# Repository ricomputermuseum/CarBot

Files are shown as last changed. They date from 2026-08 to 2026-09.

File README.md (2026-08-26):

# RICM-CarBot
This contains the Source code, Documentation, Bill of Materials, & 3D STL file for the CarBot from the Rhode Island Computer Museum. 
The code requires a Raspberry Pi Pico-W. Usually runs with a custom PCB that has two motor drivers and female headers that you can experiment with. 
The code is written for Micropython and you can use Thonny as the IDE. 

All software in the Software directory and lib/ of this repository needs to be copied to the Pico's root directory

Included is a Bill Of Materials (BOM) and a PDF for assembly and operation

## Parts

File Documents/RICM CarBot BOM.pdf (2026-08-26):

RICM Robot Car kit BOM
Qty | Item
1 | Metal car Chassis
2 | Wheels
2 | Motors w/screws & nuts
1 | Guide roller w/screws
1 | (3) AA Battery Pack w/3 pin dupont connector
3 | AA Batteries (not included)
1 | Raspberry Pi Pico W
1 | A2 3d Plastic Adapter plate (stl file)
12 | M3 x 8mm Philips Pan Washer Head (PWH) Screws
4 | M3 x 25mm plastic Standoffs
4 | Female Dupont to bare ends 20mm
1 | Diode (blue with black line)
1 | 4.7K Resistor (yellow-purple-red)
1 | 220 ohm Resistor (red-red-brown)
1 | 3mm LED
1 | Push Button Switch
2 | 8pin DIP socket
2 | L9110 IC
3 | .1uf capacitor
4 | 20 pin Female Hdr
2 | 20 pin Male Hdr
1 | 3 pin Male hdr
1 | 20pin right angle IDC connector
1 | RICM Printed Circuit Board (PCB)

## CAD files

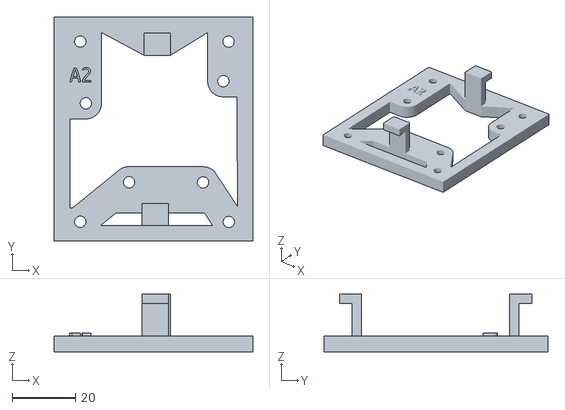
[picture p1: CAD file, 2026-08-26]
Documents/RICM CarBot-A2.stl
63.0 x 71.0 x 18.2

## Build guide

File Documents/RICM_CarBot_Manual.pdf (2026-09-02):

### RICM CarBot

(ricomputermuseum.org)

Goal:
Create a modifiable 2 wheeled robot capable of currently 4 functions:
- Ability to be remotely controlled using any web browser
- Autonomous operation by collision avoidance
- Ability to follow a thick black line
- Ability to travel in a programmed pattern.
The robot is to be built by students from age 8 on up using standard mechanical components, screws, motors, plastic components. Students will also learn how to solder a custom-built printed circuit which will be the basis of expandability and provide support circuitry to control motors and other sensors. You can switch modes with a small push button located on the custom printed circuit board. An onboard green LED flashes to indicate the selected modes. You can change mode anytime.

Hardware:
The “brains” of the robot car is a pre-programmed Raspberry Pi Pico W. The Pico was selected due to its ability to avoid program corruption when power is removed, and its size. RICM needed to have a board that the Pico could plug into that also had an onboard motor controller capable of driving wheel motors from 2.5 – 12 volts at 800ma of current per motor. No readily available boards were located that fit our needs, so RICM developed their own PCB. This custom PCB has mounting place in the middle for the Pico, (2) L9110 motor drivers, a power LED, a pushbutton. It also includes power pins for 3.3 V and 5 V as well as associated grounds to provide power to other devices such as sensors, lights etc.
The board uses GPIO pins for hardware interfacing, GPIO-14 for the pushbutton, GPIO-18-19 for the right motor and GPIO-20-21 for the left motor, for a total of 5 GPIO pins, leaving many more GPIO pins for expansion & experimentation. No external wires are needed to connect the motor drivers to the Pico as they are permanently assigned on the PCB.
On the Pico, there are also (3) analog to digital converters (ADC). The Pico uses these to convert analog signals or varying voltage, represented as numbers (0-4096) to be used for working with sensors that operate with analog voltages. These ADCs need a reference voltage to set the analog voltage against. Therefore, the custom PCB connects

1

the regulated 3.3 V of the Pico to the reference voltage of the ADCs. so the ADCs can convert analog voltages from 0 to 3.3 V to a number between 0-4096! The reference voltage can be changed by cutting a bowtie looking PCB trace and supplying the ADCs with another voltage reference. The new voltage reference must be very stable, so it is not recommended this should be done, unless you know what you are doing.
The motors will operate from 1.5 to 6 V, thus making for easy & simple battery operation. The car uses (3) AA batteries producing 4.5 V to the board and motors. The Pico needs 1.8 to 5.5 V to operate, so this battery pack is ideal for both the Pico and the motors.
The custom PCB mounts to a 3D-printed adapter plate, that is raised up so battery pack can slide under it. Software is all open source and can be modified using standard Python language at will by the student, or used as-is. All hardware, except the custom motor driver board, is readily available, as off-the-shelf parts.

Software:
With the small exception of HTML & JavaScript used for the remote control section, and pattern upload section, the software uses no special libraries and uses standard Python programming language. We chose Python because it is a good beginners programming language. All software is included with the robot and can be easily modified using the ThonnyThonny development environment. Thonny is a free software environment that is easily loaded onto any PC (Mac, Linux, Windows). Users should be familiar with this application and Python.

The robot has 4 modes it can operate in:
1. Remote control (default)
2. *Autonomous collision
3. Programmed patterns
4. *Line following
* - Extra hardware required You can select the mode with the pushbutton located on the RICM motor control board. Press it once and wait for blinking light to turn solid, then go off. Press the button X times, were X is the mode you want the robot to be in. Once selected, the LED on the Pico will flash the mode it is in. If you select a mode that the hardware does not support, or external hardware is missing, the LED will flash rapidly. You can change modes anytime.

2

OPERATION
When power is applied, the green LED on the RICM Driver board will light up indicating that power is applied. The green LED on the Pico will blink slowly indicating the default mode it is in.
To change the mode, press the push button on the RICM Driver board once. The Pico will respond with a solid light, then it will switch off. At this point, press the button to set the mode: press it 3 times for mode 3, once for mode 1 etc. The Pico will now flash the LED to indicate the current mode.
NOTE: the mode will reset to the default mode each time you apply power. This default mode can be set in the globalv.py module in the lib/ directory using Thonny.

Testing motor connections
The motor connections are the four center pins in the plastic connector at the rear of the car. Make sure the wires are connected on those four center pins or the motors will not work properly. (see Figure-1) M1 is for motor 1 and M2 is for motor 2.
Since these motors have no polarity, it’s a simple task to ensure motors are plugged in correctly. Use the remote mode and move the joystick fully forward. Both wheels should spin in a forward direction. If not, simply reverse the wires going to the motor that is spinning in the wrong direction. Once you get the forward and backward motion correct. Then test left and right wheels for proper direction of the robot. If direction is wrong, simply swap both motor wires while maintaining their orientation. Once this configuration is set, it never has to be changed. If you unplug the motors and forget where they went, you will have to re-do this step.
3v3 | 3v3 | 3v3 | 3v3 | M1a | M2a | 5v | 5v | 5v | 5v
Gnd | Gnd | Gnd | Gnd | M1b | M2b | Gnd | Gnd | Gnd | Gnd
Figure-1. Plastic connector pin assignments

3

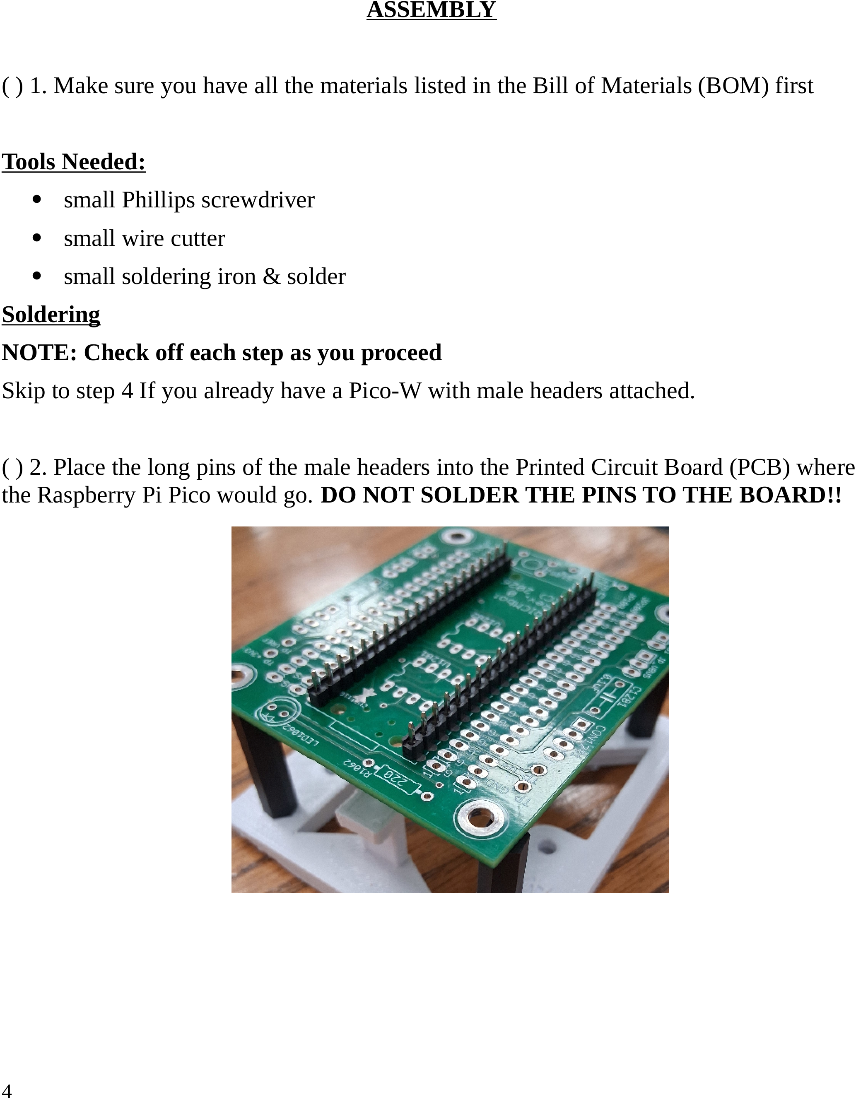
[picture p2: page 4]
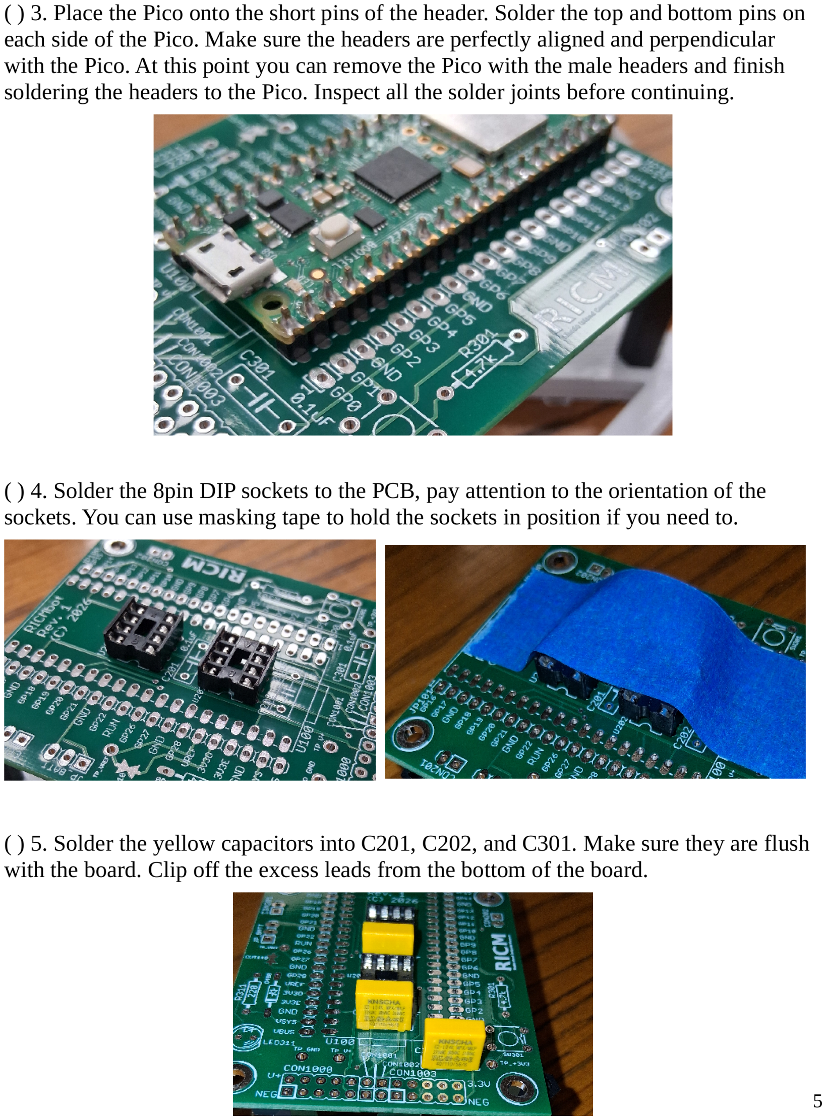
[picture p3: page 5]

( ) 6. Solder the 220 ohm (Red-Red-Brown) resistor into R311. Make sure it is flush with the board. Clip off the excess leads from the bottom of the board.

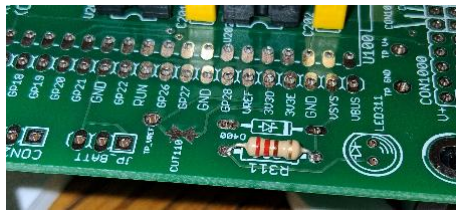
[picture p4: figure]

( ) 7. Solder the 4.7k ohm resistor (Yellow-Purple-Red) resistor into R301. Make sure it is flush with the board. Clip off the excess leads from the bottom of the board.

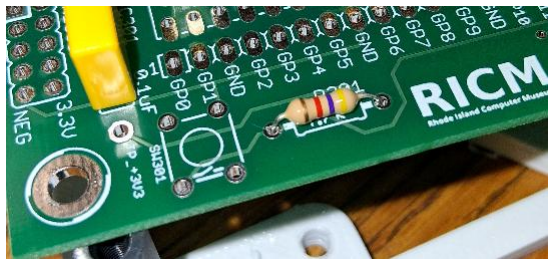
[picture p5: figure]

( ) 8. Solder the LED into LED311. All Diodes are polarity sensitive, so it’s important that they are installed correctly. Failure to install correctly will result in the LED not working. Long leg is USUALLY the Anode or “+” side of LED. “+” side of LED is denoted on the left side of this symbol Clip off the excess leads from the bottom of the board.

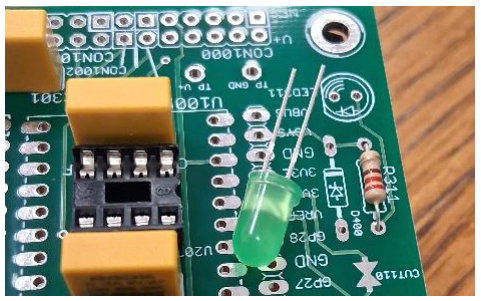
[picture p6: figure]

6

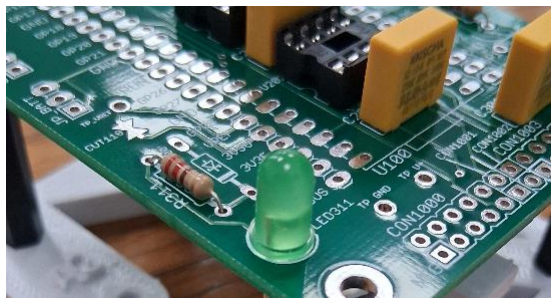
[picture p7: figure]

( ) 9. Solder the blue diode into D400. The black line on the diode needs to match the line on the PCB. If this is installed wrong, the board will not get power. Make sure it is flush with the board. Clip off the excess leads from the bottom of the board.

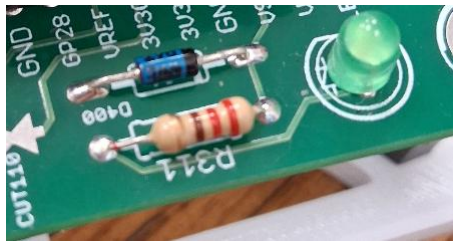
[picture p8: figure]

( ) 10. Solder the pushbutton into SW301. NOTE: it only goes in one way.

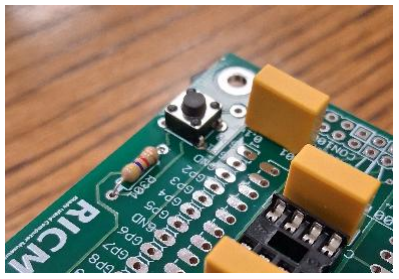
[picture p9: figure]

( ) 11. Solder the 3-pin male header into JP_BATT. The short end of the pins goes into the PCB.

7

( ) 12. Solder the right-angle IDC connector. Leave the 1st and last position empty.

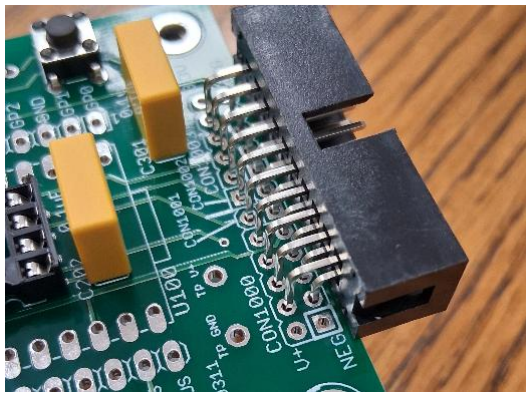
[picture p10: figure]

( ) 13. Solder the Pico female headers. Insert the headers onto the PCB, and hold them down with tape. Only solder the first and last pin at first to make sure they are aligned properly. After the two pins on each side are soldered in place and they are upright, finish soldering the headers in place.

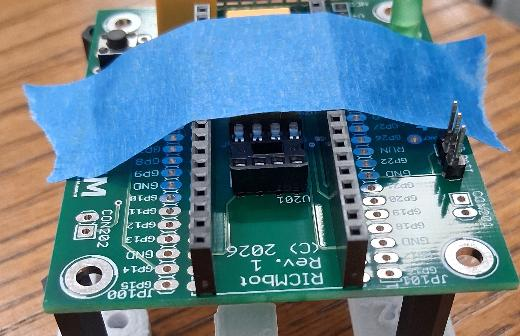
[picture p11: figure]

( ) 14. Solder the last two female headers next to the Pico headers. Use masking tape to hold them in place when you solder. Again, just solder the first and last pin and check for alignment before soldering the rest of the pins.

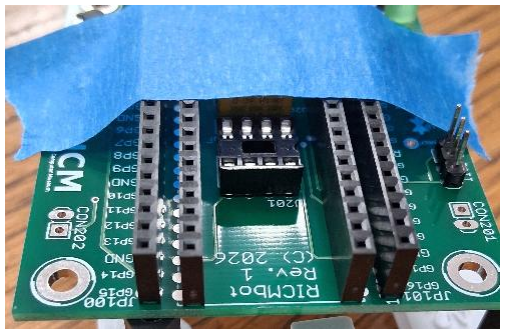
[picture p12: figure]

8

DO NOT INSTALL THE PICO OR MOTOR DRIVER CHIPS INTO THE SOCKETS

At this point you may connect that battery pack to JP_BATT. The LED should light. If the LED lights, you may continue. If not, remove the battery and check all soldering joints.

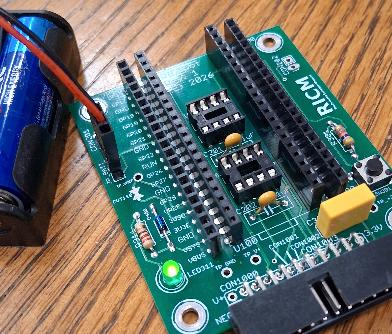
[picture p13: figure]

( ) 15. Strip off and tin about 1/8” of the insulation off each end of the female Dupont wires.

( ) 16. Remove the clear rubber hold down at the end of the motors and solder a wire to each of the motor terminals. Replace rubber hold down after soldering. Be careful not to overheat the motor connections.

9

Mechanical Assembly

( ) 17. Attach the 4 plastic posts to the top of the A2 plate using (4) 8mm screws.

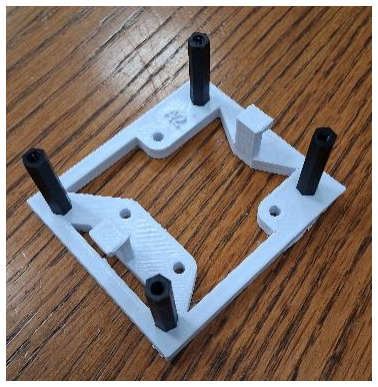
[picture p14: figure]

( ) 18. Attach the plate to the rear of car chassis using (4) 8mm screws

10

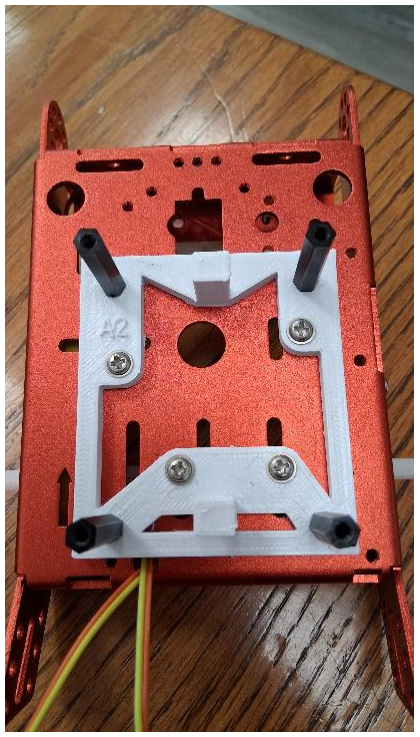
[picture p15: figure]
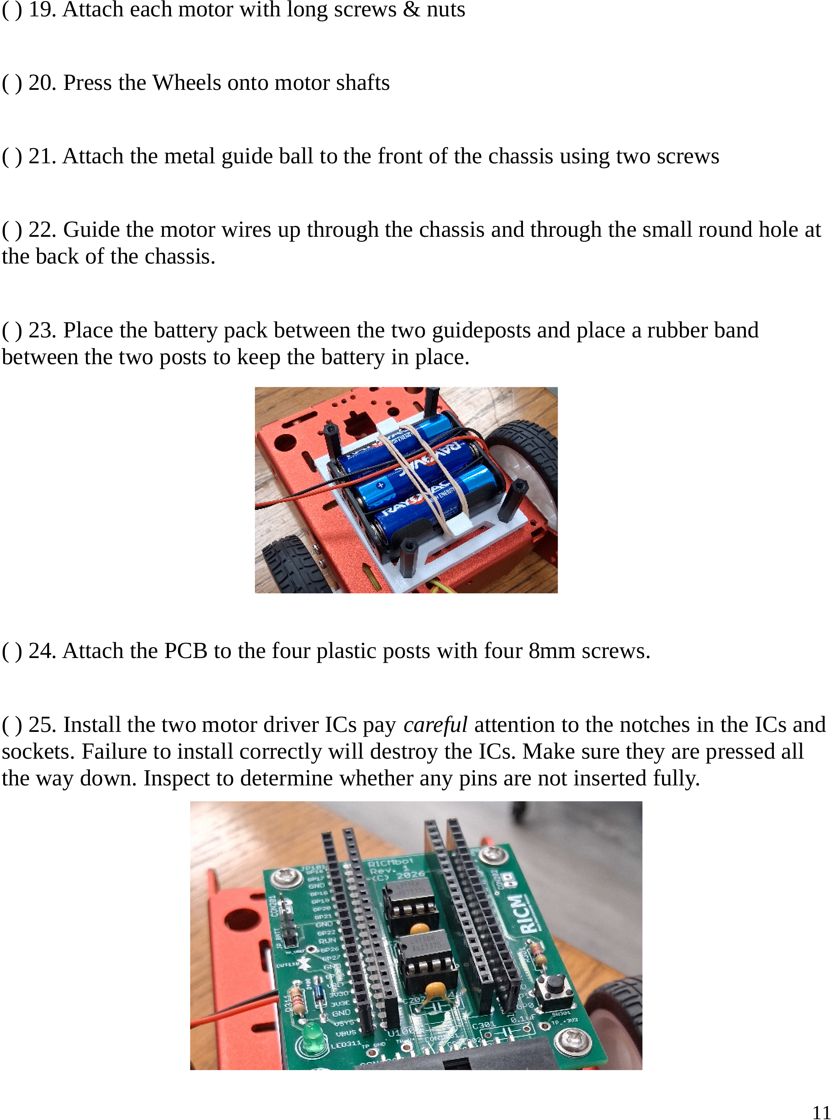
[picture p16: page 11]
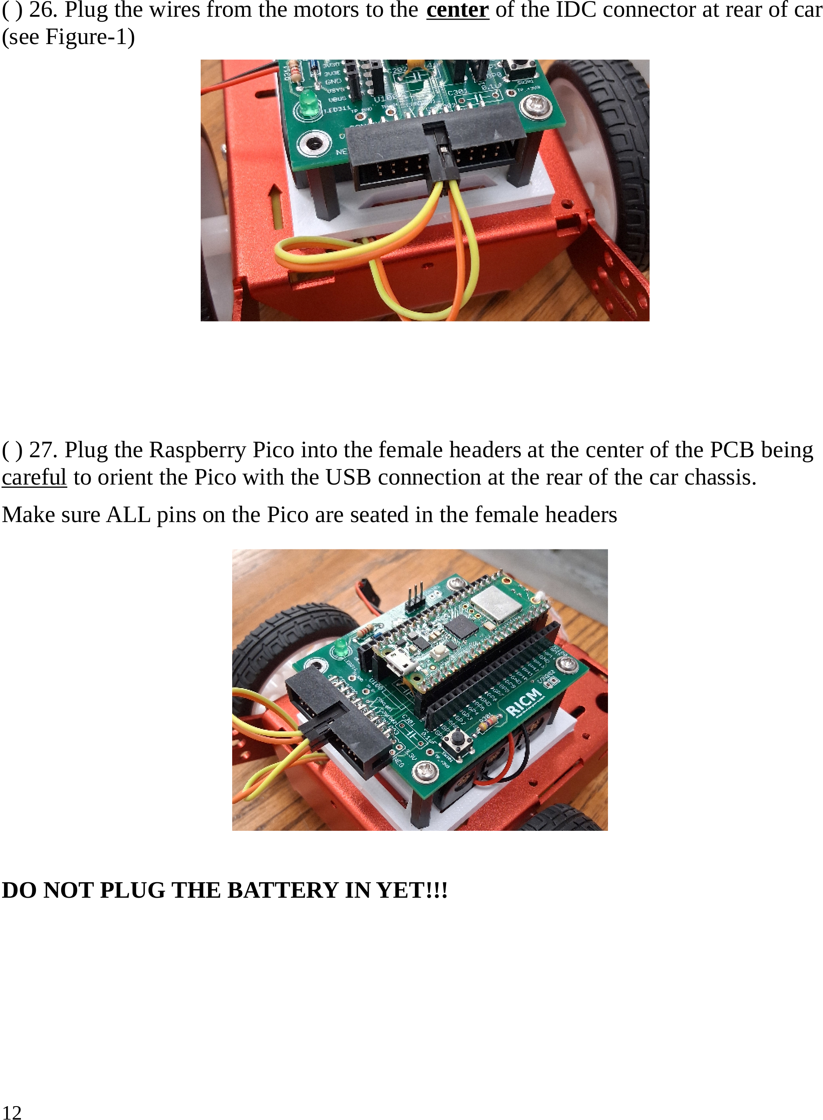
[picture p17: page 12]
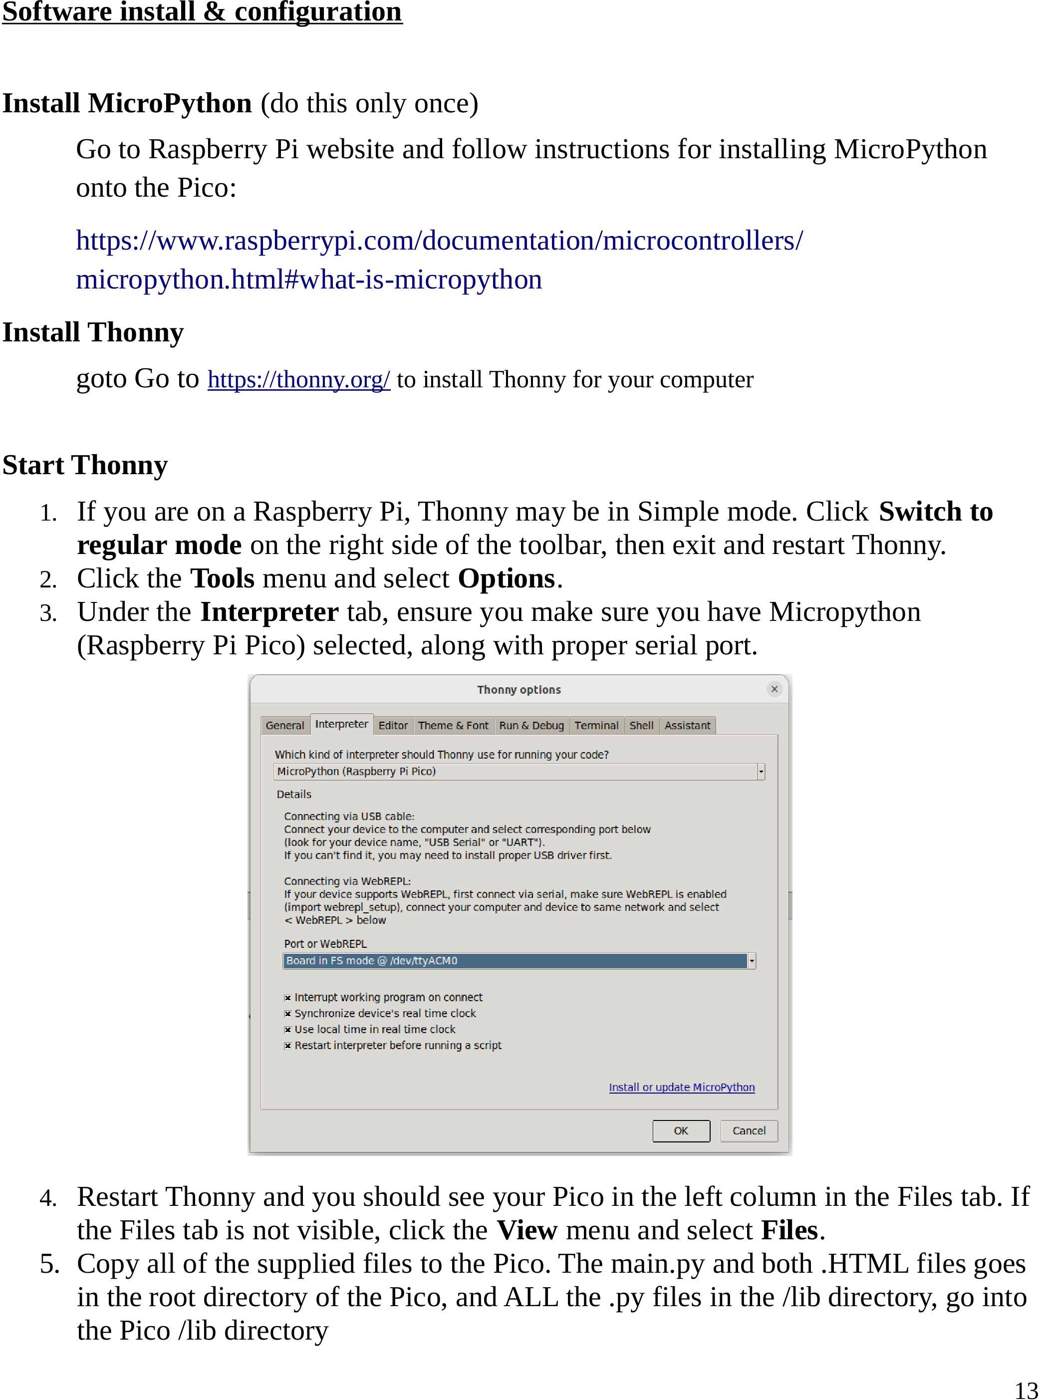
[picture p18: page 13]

Configuration:
(using Thonny)
1. Click the Lib directory on the Pico
2. Double-click the globalv.py file
3. Edit the robot name. (Robot name MUST be unique if more than 1 robot in use)
4. Edit the default mode (currently - NOMODE)
5. Save the file
6. Exit Thonny
Next: Unplug the USB cable
1. Plug the battery onto the PCB
2. The Pico should blink the default mode its in, repeatedly, until changed via pushbutton
ENJOY!

14

THEORY OF OPERATION

REMOTE CONTROL (Mode-1)
In Mode-1, the default mode, the LED on the motor control board will flash once then a delay and repeat, indicating that it is in Mode-11. The name/password of the robot is stored in the globalv.py module. By default, the password is the same as the robot name, but can be changed in the globalv module.
In Mode-1, The robot will act as a WiFi access point, and the controlling device (i.e. laptop, iPad, phone, etc.) must be on this network. The SSID and password for the robot will be something like “Robotxxx” where xxx is a number like 001, 007 etc. This can be modified through software changes. The password for the access point is configured to be the same as the name you see when trying to connect. The XXX is written on the Pico, so it does not need to be remembered. Once connected, simply open a browser and type in “robot.run” in the URL line. Only one user at a time may connect with their browser to allow exclusive control of the robot. Once connected, the user will be presented with an onscreen Joystick, allowing you to move the robot using a simple finger movement. Once you take your finger off the screen, the joystick will go to a neutral position and stop the robot. This is a fun way to control the robot.

Detailed operation:
The main.py module calls the REMOTE_MODE function in the remote.py module. This function should return a code of either a 0 (normal) or a negative number, indicating an error.
Once the REMOTE_MODE function is called, it will set up an access point, DNS server, and web server in the ws_stuff.py module. This module is responsible for all WiFi activity. When the services are activated, the function waits for a connection from a browser. Typically when a browser starts, it looks for a captive portal page. This has to be ignored via the DNS server to allow the user to type in a URL. The URL name that is used is stored in the globalv.py module. When the URL is typed in, the browser sends this to our DNS server, which resolves the name to the IP address of the Pico, where it connects to the HTTP server. The server will send the root document to the browser. This document is stored on the Pico root directory as remote.html. This web page must be limited to 6k in size. The web page also has some JavaScript (JS) associated with it. It is the job of the JS to handle communications from the joystick control to the remote.py module.
Since web traffic is VERY “chatty”, normal web conversation won’t be fast enough to handle the required speed. Therefore, the movement of the mouse was scaled to allow

15 for +10 and -10 steps, both forward, backward, side to side. When the data is sent to the Pico it is scaled back up to +100 to -100 in all four directions, because the motor driver expects movement as a percentage. This greatly reduced the web traffic that would have occurred. Web traffic uses TCP, which requires each packet of data received to be replied with an “ACK” before the next packet could be sent. Luckily the Pico TCP socket scheme handles this for us.
The “joystick” format is more intuitive to the user, so that’s the main reason why it was chosen. The user can close the browser anytime and the software will close the connection and wait again for another connection and start all over again. If the user presses the onboard push button on the PCB, the robot will shut down all services and allow the user to change the mode. This is a very simple mechanism as well.
The remote.py module requires the ws_stuff.py, globalv.py, and return_codes.py modules, in addition to the standard MicroPython network, socket, and gc libraries.
See the function listings for remote.py to see what each function does.

16

Pre-Programmed Patterns (Mode-2)
Mode-2, the LED on the Pico will flash TWICE times then a delay and repeat while in this mode, indicating it is in Mode-2.
This is another web-based module. Therefore upon selection of this mode, the main function will call get_pattern in the pattern.py module. This function will set up an Access Point (AP), DNS server (DS), and a webserver (WS). These functions are in ws_stuff.py. This module is also used with the remote module, so be careful if you modify it. Once the servers are active, the function waits for a web connection. Just like the remote mode, you first need to connect to the robot AP. Use the SSID name and password that is set in globalv.py. Without modification, the SSID and password are the same, typically used is RobotXXX, where XXX is a number like ‘007’. Your device may complain that there is no internet connection, which is fine for our purpose. Once your device has been connected to the AP, you need to open a browser to upload a pattern file to the robot.
When a browser is opened, it will attempt to search for a “captive portal”, which our DNS will ignore. You type into the URL line on the browser, our URL which is “robot.run”. This name is specified in the globalv.py module. If you modify this, do NOT use .com, .org .net etc. as your browser will want to connect via HTTPS instead of HTTP. HTTPS is way too complicated for the Pico to handle at this time. Upon successful connection, the browser will ask you for a file to upload using a standard file locating mechanism. Upon file selection, the browser will send the file a line at a time, checking each line for proper commands and format that is in the cmd_table.py module. If anything is incorrect with a command or format, the import will fail with an error that needs to be corrected. If the line is correct, it is encoded in an internal pattern string. Once the file has been successfully imported, the robot will follow this pattern endlessly, until a different mode is selected or power is removed. Once the pushbutton is pressed, the pattern data on the Pico will be cleared and memory reclaimed. The pattern module is very modular, allowing for new commands to be added, modified.
The user can write their own pattern for robot to follow.
Patterns can be created in a separate text file and name it whatever you like. ie. pattern.txt. The file is a plain text file with 1 command per line. Comments may be added to file of after a command. Comments begin with a “#” character, same as Python comments. It will ignore blank lines
Current pattern commands:
SXXX = Speed (0-100)
*Once Speed setting is made, it stays that way until changed. Speed 0 = stop

17

WXXX = Wait in Milliseconds L = Left turn
R = Right turn
F = Forward
B = Backward
BBn = Begin a block. (n is 1-10)
EB = End a block definition
Exn = Execute a block (n is the block number)

Sample file for a square:

# ------------------- Define a block ----------------

BB6 | # begin block 6
S100 | # set speed to 100%
F | # move fwd
W250 | # wait 1000ms | (1 second)
S010 | # Set speed to 10%
R | # right turn
W25 | # wait 25ms. This is how long the wheels stay in this turn
S0 | # stop
EB | # end this block - 6

# ------------------ end this block --------------------

# define square block

EX6 | # turn 1
EX6 | # turn 2
EX6 | # turn 3
EX6 | # turn 4

w2000 # wait 2 seconds after 4 turns

#------------------------- Repeats pattern file endlessly

By modyfing the cmd_table.py it is possible to add more commands, such as turn on/off headlights, turn on/off turn/brake lights etc.
18

Autonomous collision avoidance (Mode-3)
Mode-3, the LED on the Pico will continuously flash THREE times, then a delay and repeat while in this mode, indicating it is in Mode-3.
The robot will move along the ground at full speed, on its own, sensing any obstruction via an ultrasonic sensor, then as it gets close to an obstruction, it will slow down, giving the opportunity for the obstruction to move away, if not, the robot will stop, back away, and turn away from the obstruction, then continue on its journey in a forward motion. This mode will continue forever until changed via push button.
The Collision Avoidance (CA) module requires extra hardware and mounting material, such as a 3.3 V ultrasonic sensor, mounting adapter and wires to plug into the expansion headers. If this sensor is not present, the onboard LED will flash rapidly. During operation in this mode, the sensor sends out ultrasonic (40 kHz) sounds and listens for reflected sounds. The time difference from when the sound was sent, to the time it is sent back, indicates how far the object is. The intensity or “loudness” of reflected sound, indicates how large an object is. This is typically called a “ping” just the same way submarines detect objects in the water.

19

Line Following (Mode-4)

Will be implimented in next release
Mode-4, the LED on the custom printed circuit board will flash four times then a delay and repeat while in this mode, indicating it is in Mode-4. In this mode, the robot will follow a black line drawn on a light background.

20

TECHNICAL DOCUMENTATION
GENERAL: As mentioned in the operation part of this manual, most of the software is written in standard MicroPython that runs in the Raspberry Pi Pico W. No special libraries or dependencies are used. The software is modular by design, lending itself to easy modification. A program called Thonny is used to program the Pico. Thonny is a free program that runs on Apple, Windows, or Linux computers. The Pico is attached via USB cable to the computer.
Any setup variables such as the robot name, default startup mode, etc. are in a file called globalv.py located in the /lib directory on the Pico. There is also a DEBUG variable which can be set to True, to aid in debugging the code, through various print statements to the console.
Using the custom RICM motor driver board, an import in main.py must import ricmboard, as Platform, the ricmboard will import L9110 as the motor driver. The motor driver will actually control the motors.
Once a Platform and Motor have been established, the software will know how to control the robot. As per standard Pico operations, as soon as power is applied to the Pico, main.py will be executed.
Different modes of the robot are selected via the onboard pushbutton of the RICM board. Press it ONCE to enter the change mode. This mode will be indicated on the Pico as the LED stayig on for 2 seconds, followed by going off. You then press the button for the mode you want to be in. ie press 3 times for mode 3, etc. after you stop pressing the button, the Pico will enter that mode and constantly flash the mode number while it is in that mode. Any software that is running, needs to poll the “button_pressed” variable on the globalv.py module. If this variable is True, you must clean up your code, stop any motors, and just return to main.py with a return code of 0 (NORMAL). Any negative value will be deemed an error of some sort, where as any positive value would indicate some sort of status value.
Under Mode-1 (remote control) and Mode-2 (pre-programmed pattern control), WiFi and Web Servers are implemented. Using these two modes, some small JavaScript code is used to run on the users web browsers and is sent along with the web pages sent. In order to use these modes your device must be connected to the Access Point(AP). The name and password for the AP is specified in globalv.py. Once you have connected to the AP, simply open a browser and type in the URL name that is specified in globalv.py, the default is “robot.run”. Once you are connected, you will be presented with a joystick for remote control in the remote control mode, or a file upload form to upload a pattern to follow in the pattern follow mode.

21

The software lends itself to be very modular, so features can be added or removed without breaking everything else. You can run it on different motor chassis, using different motor controllers etc. that is the basic function of the car robot. For example if you want to use a different motor controller such as a stepper motor, you would need to remove the L9110 chips, wire up you motors to your controller and plug your wires into the Pico headers, write your own motor controller driver and import it into ricmboard.py. The controller only requires two functions, init() and drive(d,t). Also, you need to name your driver. D is the difference between left & right motor, and t is throttle. MAIN.PY
This is a small module that runs on power up. It sets up the base environment, and passes control to the different modes, which is either the default mode, set in globalv.py or the mode that is set from ricmmode.py.

RICMMODE.PY
This module is responsible for blinking the LED as a regular timer interval regardless of what the application is doing. It blinks the Pico LED with the current mode. It also has the ability to make the onboard LED Flash rapidly in the event something goes wrong wit a mode setting. Ie setting the collision avoidance mode without the ultrasonic module being present, etc.

RICMBOARD.PY
This module is unique to the RICM motor driver board. It also loads the L9110.py module, as this is the actual code that talks to the motors. This module also sets up the pushbutton interrupt handler. This pushbutton is unique to the RICM Board. The Interrupt handler just sets the button_pressed variable located in globalv.py. This variable needs to be checked by any application and stop operation and return back to the main.py for proper mode handling. The actual mode switching is performed in the ricmmode.py module called from the main.py module.

L9110
This is the module that drives the motors. It has only two functions, init() initializes the driver if needed, and drive(d,t), actual driving of the motors. This module sets up Pulse Width Modulation (PWM), the GPIO Pins that are used, PWM Frequency, and Duty Cycle.

22

To make the motors move, the drive function is used. It takes two parameters, d and t. d is the differential, 0 to -100 for the left and 0 to 100 for the right. t is the throttle. 0 to 100 for a forward motion and 0 to -100 for reverse. For example, if you want to move forward, where each motor gets the power, set d to zero, and t to whatever speed you want from 0 to 100%. If you want reverse, again, set d to zero, and t to the speed you want to go backwards from 0 to -100. To stop the motors, set d to zero and t to zero.

REMOTE.PY
This module is called when user is in mode-1 (as defined in globalv.py). This module is the heart of the remote control function. Upon successful web connection, the module will read remote.html into memory and serve it to the user’s web browser. remote.html also contains some JavaScript that mimics a joystick control. As the user moves the “joystick”, it will send updates to the Pico to make the motors move. When the user removes their finger from the joystick, it returns to its central position, and sends a motor stop command, causing the robot to stop any movement. Each pixel of movement is translated to 0-10 to minimize web traffic. The Pico can not handle fast, tiny, data transmission packets over WiFi, thus the joystick movement had to be scaled down. Once the Pico receives the X/Y position data, it is converted to a 0-100% scale and also to a differential drive for each motor. This information is sent to the motor driver, in the case of the ricmboard, this will be the L9110.py motor driver as two parameters, differential and throttle.
If you view the joystick as four quadrants, anything above the middle is 0-100, meaning motors will move in a forward direction. Anything below the middle will be 0 to –
100,
which means motors will spin backwards. Anything to the right will be 0 to 100 and result in more speed to the left motor, thus pushing the robot to the right. Anything to the left of center will be 0 to-100, resulting in more speed to the right motor, thus pushing it to the left.
Several print() statements are sprinkled throughout this module to aide in debugging if the variable “debug” is set to True in the globalv module
This module also frequently check the global variable button_pressed located in globalv.py. This value will be True if the user has pressed the button for a mode change. The module needs to clean up and exit if the button is pressed. This module will stop the access point (AP), web server (WS), DNS server (DS) and stop all motors before returning back to main.py.

23

PATTERN.PY
This module is called when user is in mode-2 (as defined in globalv.py). This mode allows a user to upload at pattern to follow autonomously. Once a file is uploaded, the CarBot will immediately follow this pattern forever, until mode change, or power is removed. If the mode gets changed, the pattern file will be deleted from memory and must be reloaded. This module does several things, first it turns on an access point (AP), a DNS & Web server, so the user must connect to the CarBot via a web browser and upload a file. This can be done from a cell phones, tablet, or computer. This module will validate the pattern file during the upload. If any errors occur in this process, the pattern file upload is aborted, and the line and error will be displayed, allowing the file to be corrected. This module deals a lot with pointers and tables, so be very careful modifyin this module. As each line is sent from the browser, the line is validated for errors, such as invalid commands, command values are out of range, proper formatting, bypassing blank lines or comments, command block definitions, etc. Once the line is validated, it tokenizes the command & any variables, and adds it to the growing internal text line. These tokens consist of index pointers to a command table for later processing.
This module imports cmd_Gvar.py which has variable in common to to the validator and runtime functions. The import called cmd_table.py, is a table that has all the possible commands that can be used in the pattern table. This table is crucial to validation and operation. On validate, the command, or mnemonic is is checked against his table. If a match is not found, the entire command line is rejected and an error is sent back to the user when uploading. If the mnemonic is found, the index of this table entry is saved, and the rest of the command line is checked for any variables. Each variable has a min/max value, so the command line is checked for variable to be in range. Ie Speed has a variable that sets the throttle speed. It has a min value of -100 to max value of 100. if the user specified a throttle of 256, it would be out of range, and therefore an error and the command line will be rejected. Since this variable can fit into 1 byte of space the command will be tokenized as 1 byte for the pointer into the command table, and byte for the variable. This save memory space and allows for optimized run time.
After the entire pattern file is loaded into memory as a string of tokens, the current pointer fo the command string is set to zero and the pattern will now run. During run time, the byte is pulled from the string and it is used as a pointer into cmd_table.py to find the function to process. The cmd_table.py is set up as follows:
Elements of cmd_table:
- 1st = Mnemonic code for the command, this is what is used in the pattern text file
- 2nd = Display text for the command, can be used to list a pattern file
- 3rd = Minimum decimal value for the command

24

- 4th = Maximum decimal value for the command
- 5th = # of packed bytes for the variable. 0 for no variables for the command
- 6th = Name of function to call in cmd_funcs.py !! MUST be defined in cmd_funcs.py !!
As specified in the table, the function to run MUST be defined in cmd_funcs.py if there is no function to run, you must specify f_undefined to satisfy the run time process. After each process of a command, a function must call nxt_pat_ptr so the process knows where the next command to process is located in the pattern string.
A repeat command is being worked on to allow commands to be repeated within a pattern. There is a command that defines up to 10 command blocks with a begin block (BB#) command. Where # is a block number. This allows a user to make blocks of code and run each block with just one command called Execute Block (EB#).
Making tables allows expansion of commands, such as LT with a variable of 0 or 1 meaning to turn of or on a left turn signal.
cur_pat_ptr------/------> Pattern string | G.cmd_ptr--/---> CMD_TABLE
nxt_pat_ptr-----/ | (one or more bytes) | / | |-----cmd_nmemonic
prv_pat_ptr----/ | pat_cmd ---------------------->/ | | |-----cmd_display
| pat_var (1 or 2 byes if any) | | |-----cmd_min
| | | |-----cmd_max
| | | |-----cmd_xbyte
| | | |-----cmd_function
* pat_ptr(s) are merely pointers into the pattern string

25

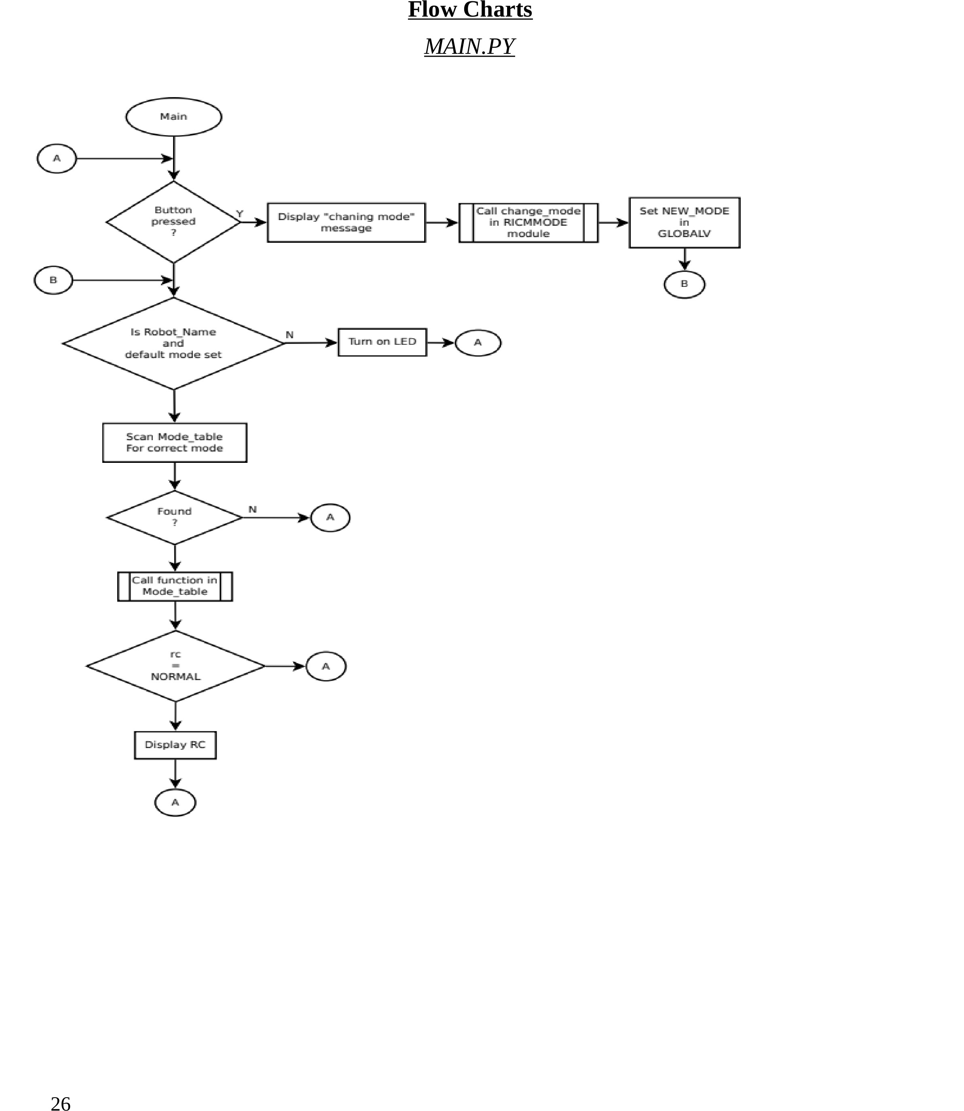
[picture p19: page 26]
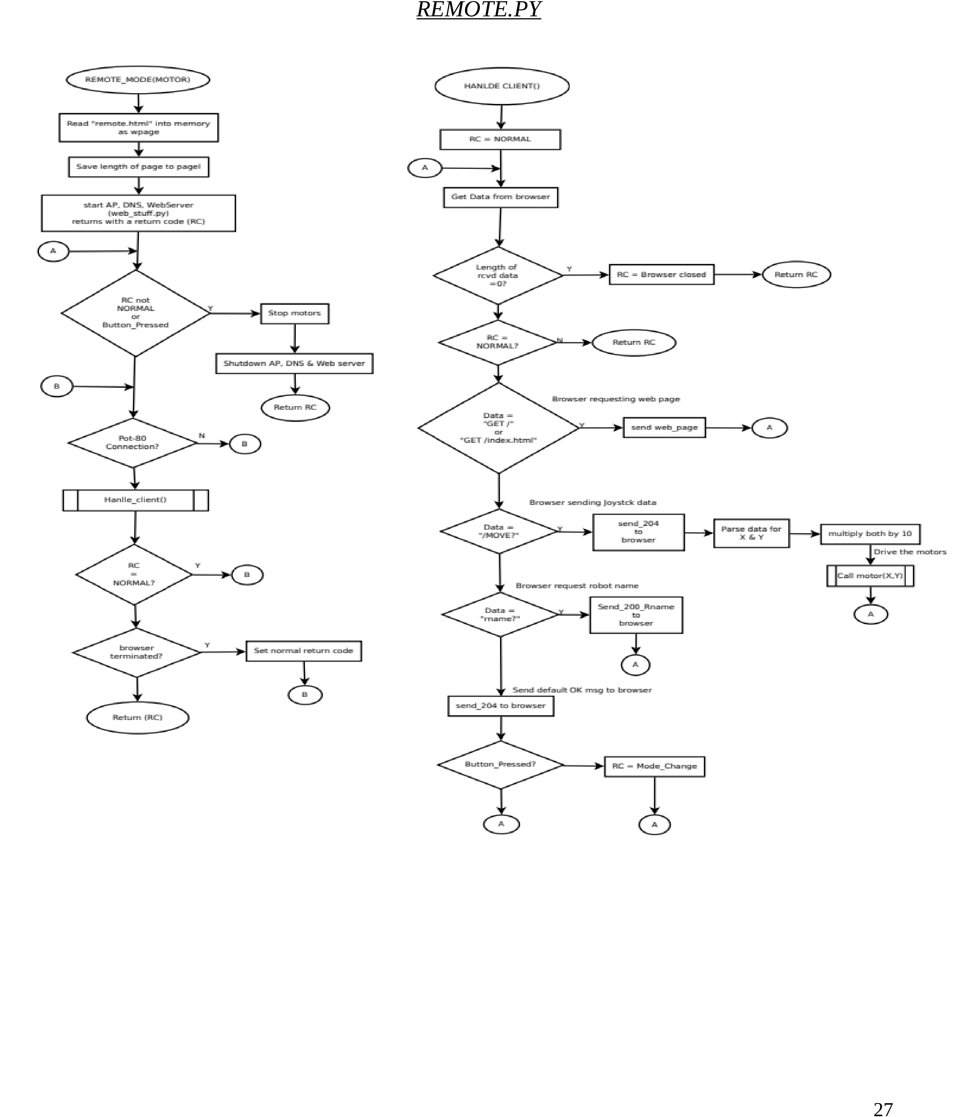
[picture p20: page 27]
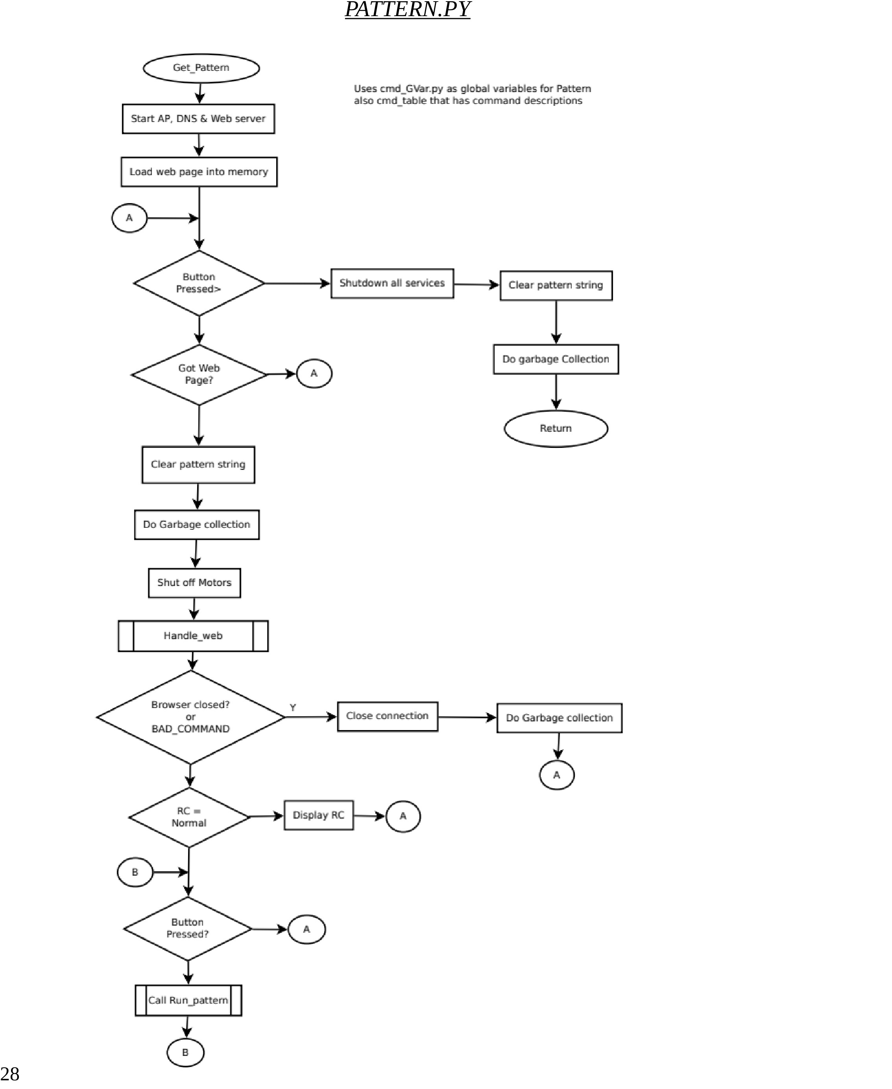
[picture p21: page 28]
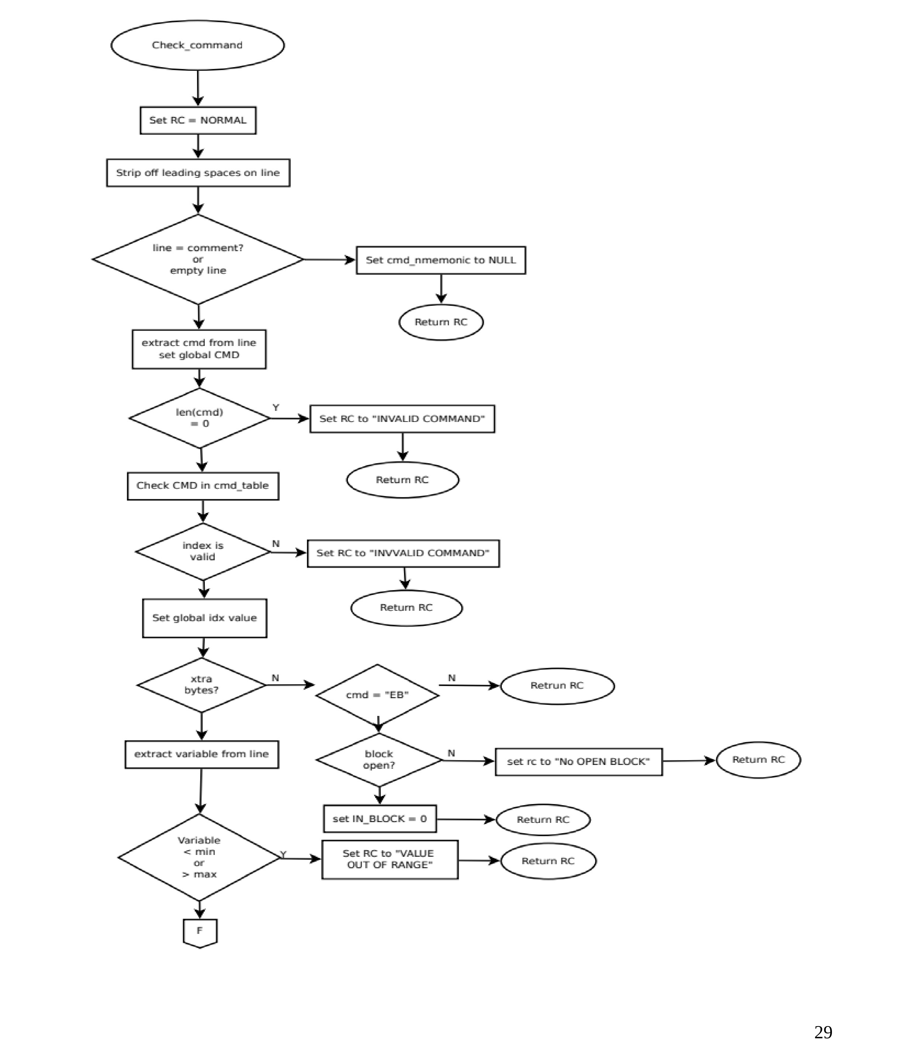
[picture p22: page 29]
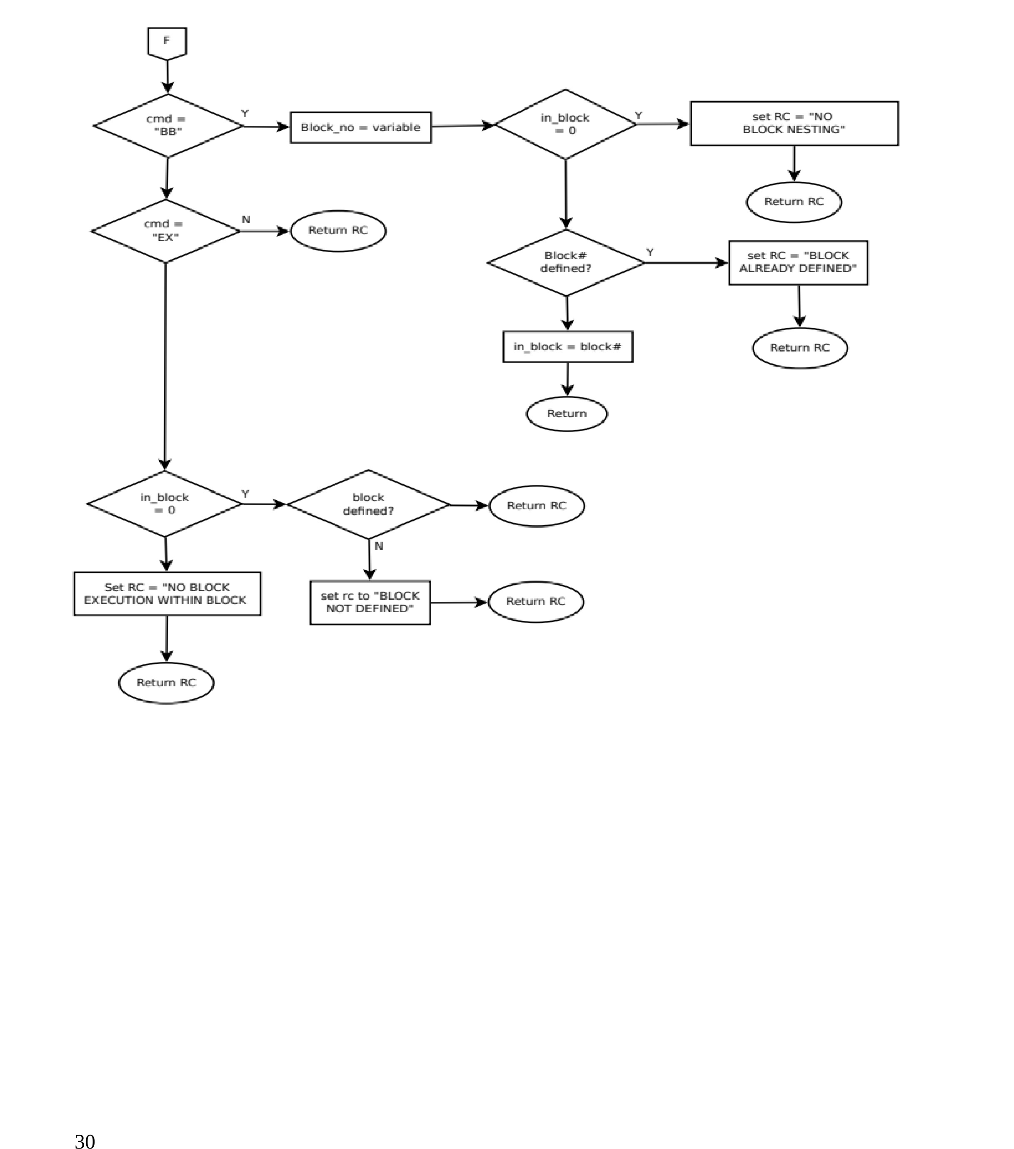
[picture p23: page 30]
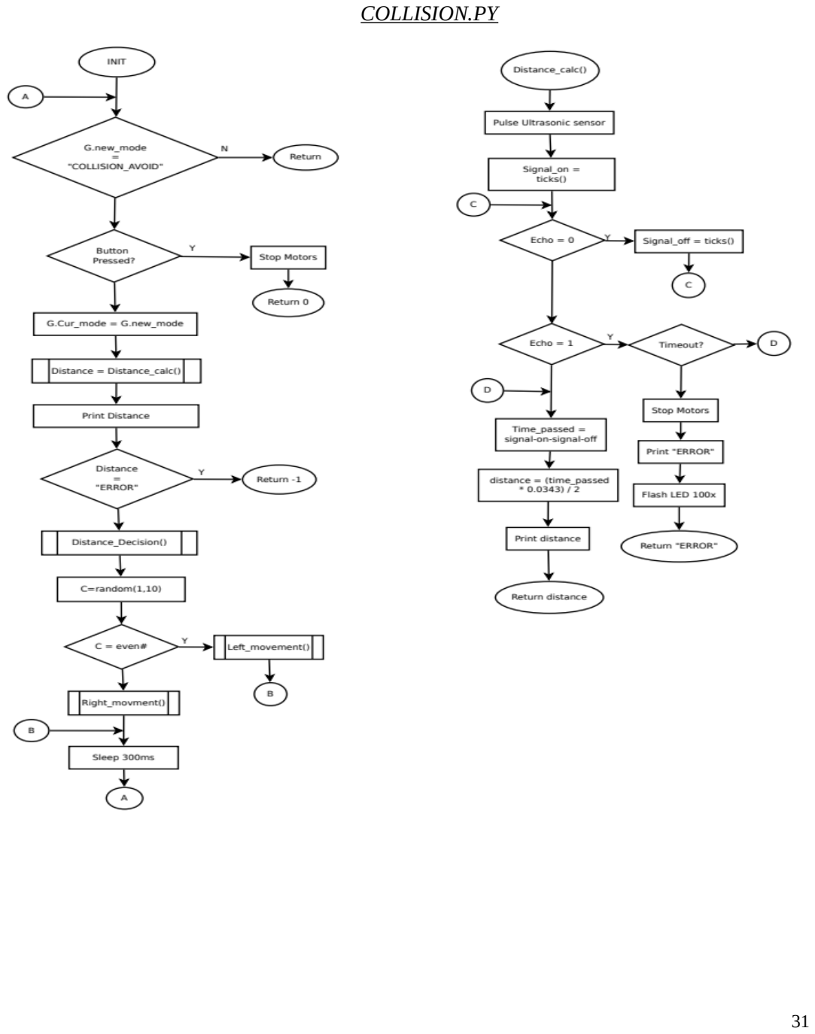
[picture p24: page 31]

COLLISION.PY

31

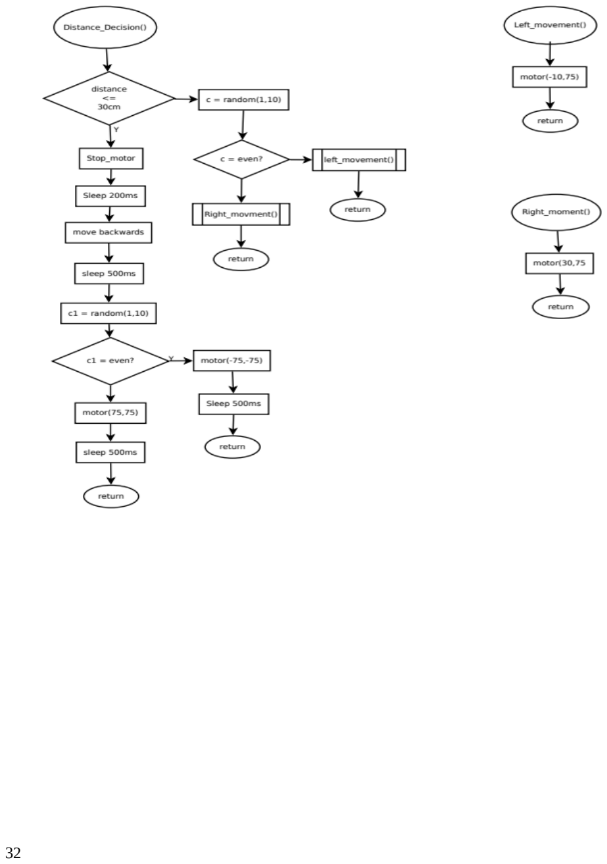
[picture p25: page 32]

32

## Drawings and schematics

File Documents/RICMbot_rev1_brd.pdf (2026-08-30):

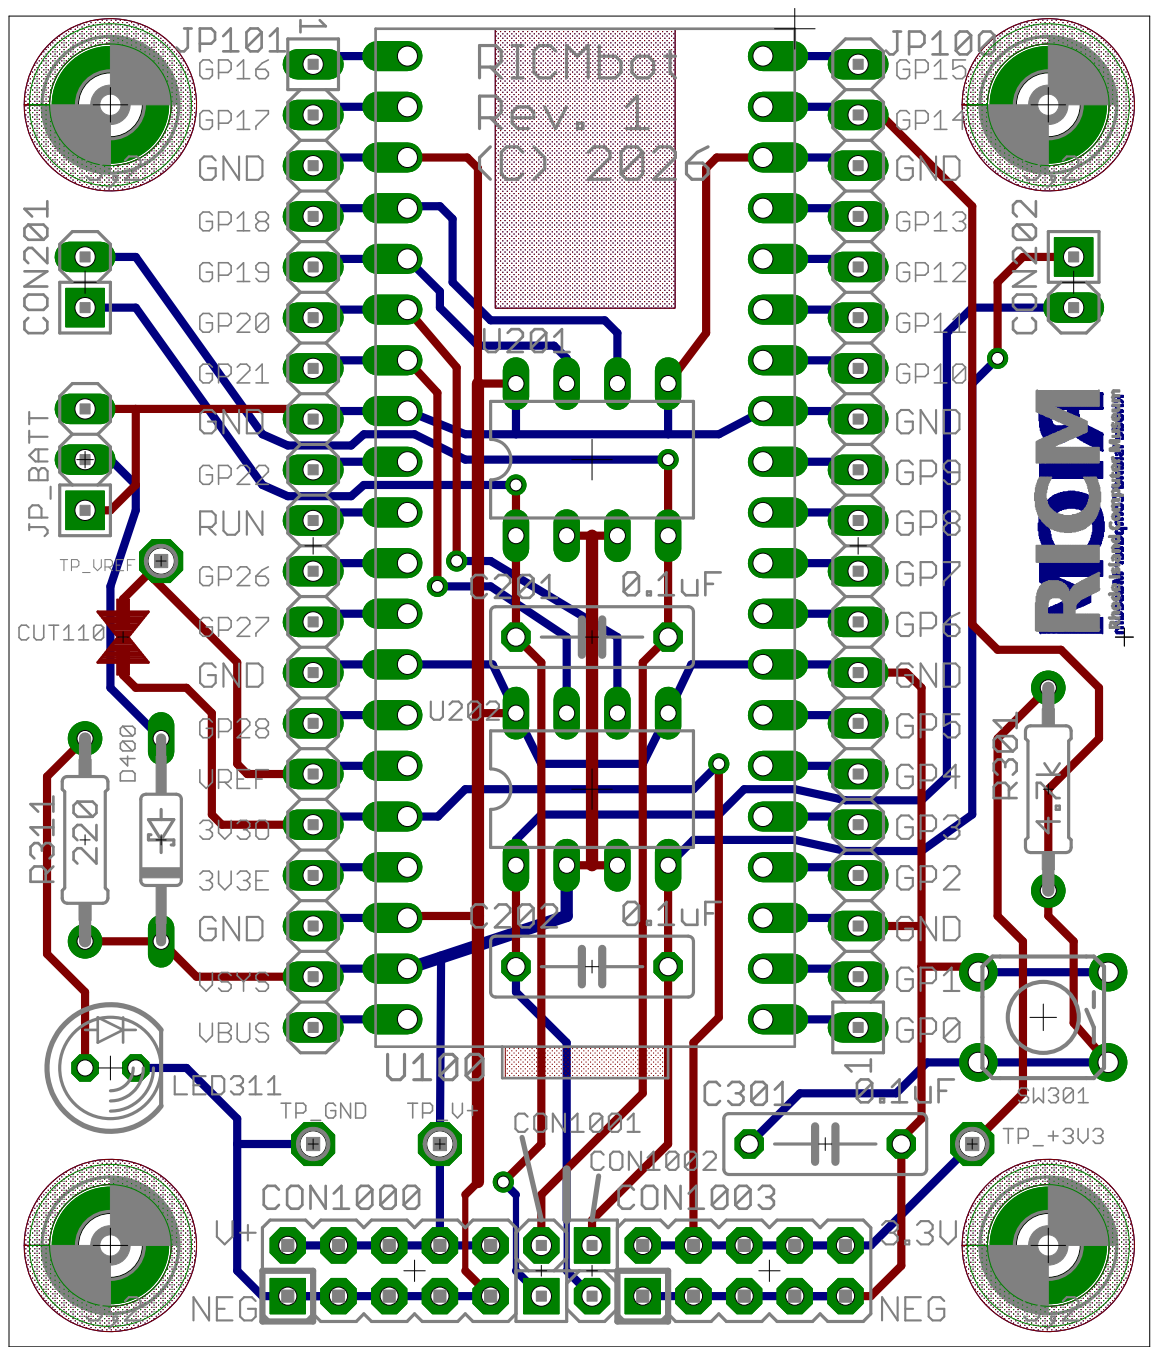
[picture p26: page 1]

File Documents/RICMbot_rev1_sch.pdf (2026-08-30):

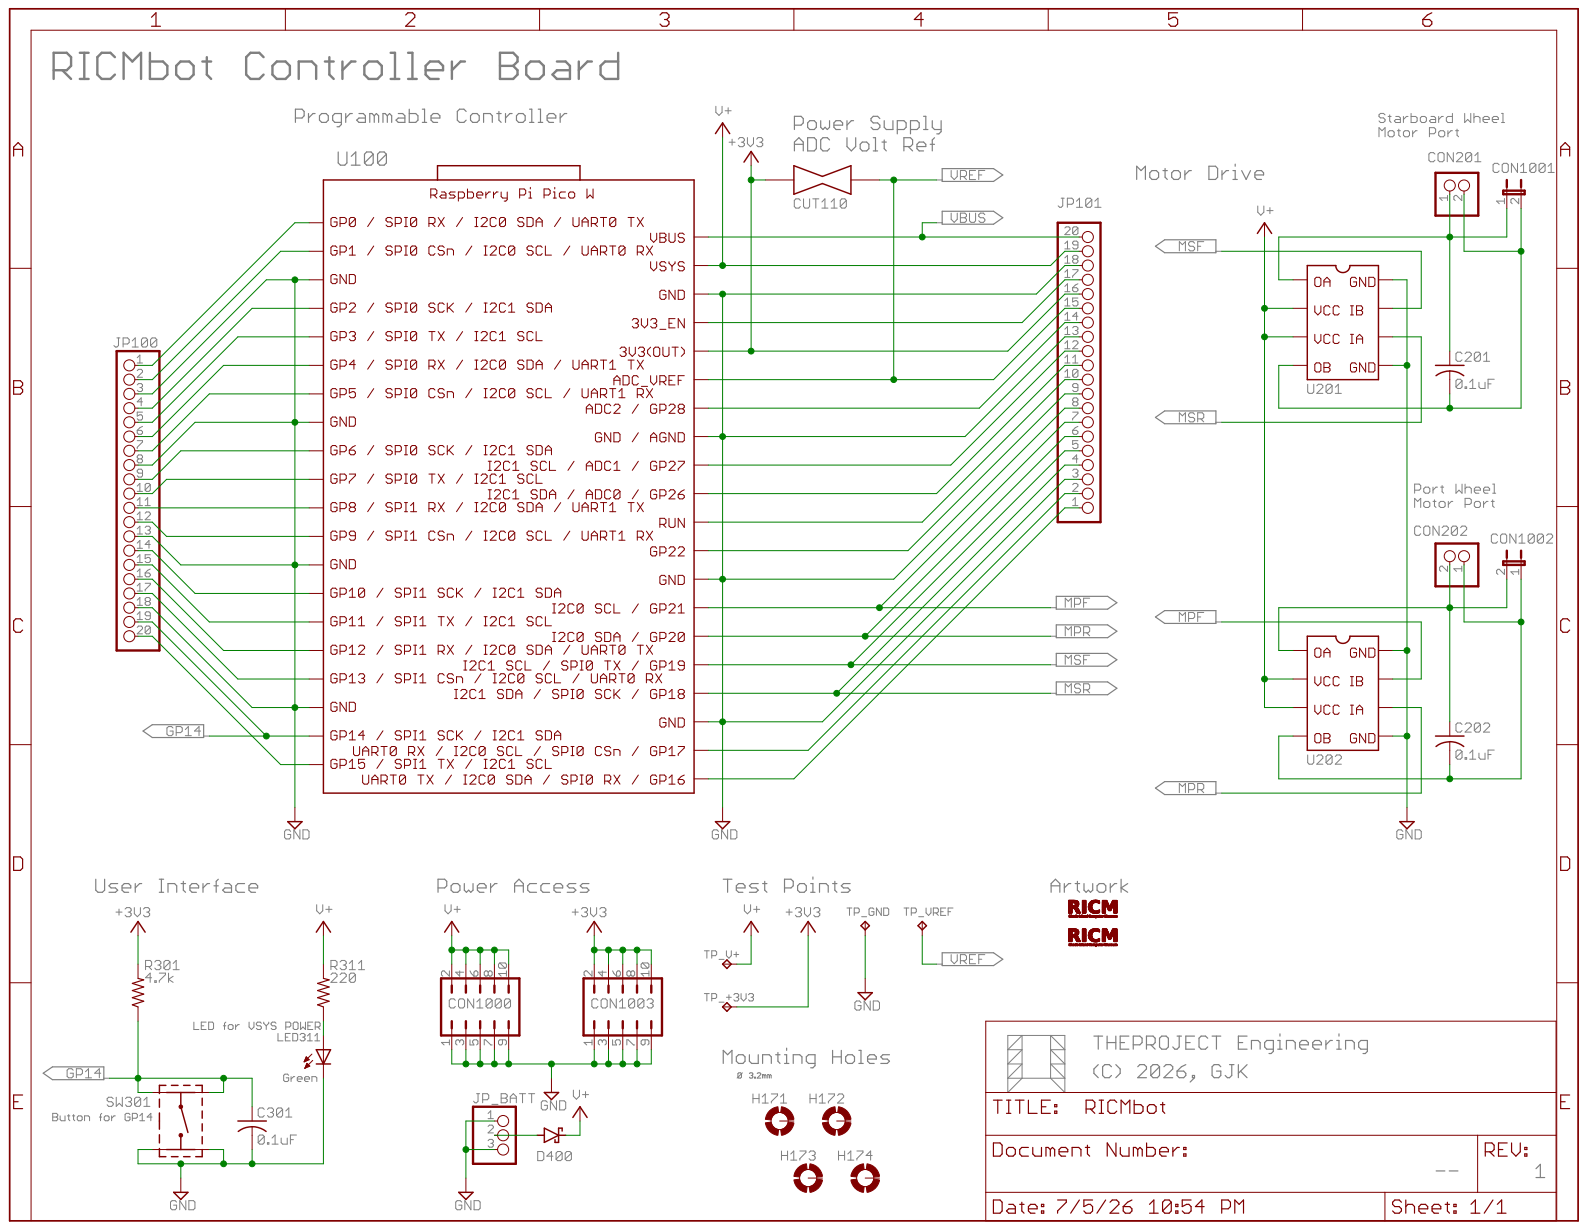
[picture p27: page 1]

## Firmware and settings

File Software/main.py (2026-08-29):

#^ MAIN.PY ******************************************************************************
# *			Rhode Island Computer Museum (RICM)
# *				    RICM CarBot
# * Version: 1.0
# * Date: 3/12/2026
# * By: Ray Young
# * For: Rhode Island Computer Museum (RICM)
# *
# * This is the main program for a simple robot car
# * its modular in design so it can use many different motor driver boards & Platforms
# * provided that a driver for the board is written
# * A platform is capable of using many external motor drivers or use onboard drivers
# *
# * There are also three platforms that can be used:
# * 1. RICM Pico breakout board designed by Grant Koboszka@RICM
# * 2. RoBro - a single board robot also designed by Grant Koboszka@RICM. Has built in sensors
# * 3. picobreakout - similar to the RICM board but uses external motor driver ie. FeeTech
# *
# * Currently there are two motor driver boards:
# * 1. FEETECH simple two motor board
# * 2. L9110 RICM custom board with two onboard L9110 chips as motor drivers
# *
# * Currently the program can control the robot in 4 different modes 
# * 1 - Remote control. By using any web browswer, the user can control the car via
# *     a joystick type of control   
# * 2 - Follow a Pattern. The robot will move along an upload pattern, using various
# *     pattern plans. The user can upload a pattern to the robot where it will stay
# *     until it is overwritten by a new one. Read documentation for the various
# *     commands you can give it
# * 3 - Collision avoidence. With an ultrasonic module, the car will autonumously
# *     drive on the ground avoiding any obsticals it encounters. Using the Ultrasonic
# *     sensor, it senses the distence of an object, stops, turns, and detects
# *     if it can move in that direction. if not, it turns again, until no object
# *     is in its path. It will ten continue forward until another object is detected
# * 4 - Line following. By drawing a dark line with a magic marker, the robot will
# *     follow alog the line (not yet implimented)
# * Mode selection is done via an onboard pushbutton on the custom RICM board.
# * Modes can be changed at anytime
# *
#~ **************************************************************************************

import globalv                 # load global values
# import ricmboard as Platform
import time                    # time functions
from machine import Timer, Pin
import gc                      # garbage collection. we will run manually
import Remote                  # Remote control modual
import Pattern                 # Pattern following module
import ricmmode                # code for mode switching

try:
   import linefollow          # attempt to load Line Following Module
   LFunc = linefollow.LF_run             # This mode requires additional hardware  
except ImportError:
   LFunc = ricmmode.flashit  
     
try:
   import ultrasonic          # attempt to load Collision avoidance mode
   CAFunc = ultrasonic.init              # This mode requires additional hardware 
except ImportError:
   CAFunc = ricmmode.flashit 
          
#               MODES Table
# Table entries: Mode number, Function to call
#
# Add tale entries for new functions...
#
MODE_TABLE = [
	1,Remote.RemoteMode,    # Remote control
	2,Pattern.get_pattern,  # Pattern follow
	3,CAFunc,               # Collision Avoidance
	4,LFunc                 # Line Following (not implimented)
	] 

# ***************************** HERE WE GO! **************************
# Modes will be set via interrupt push button
# ********************************************************************

# ----------------------------- INITIALIZE ----------------------
# Platform  = __import__(globalv.Platform)  # which platform using
rc = globalv.Platform.motor.init()     # initialize motor controller
print("Mem allocated:", gc.mem_alloc(), "Free:",gc.mem_free())
print("Platform:",globalv.Platform.Name)
print("Motor Driver:",globalv.Platform.motor.Name)
x     = time.localtime()
date  = str(x[1])+"/"+str(x[2])+"/"+str(x[0])
ltime = f"{x[3]:02d}:{x[4]:02d}"
print("Current Date/Time:",date,ltime,"\r\n")

# Mode setting will be done anytime if using the RICM board via a push button,
# with default mode set in globalv.py
# ------------------------ MAIN CODE -----------------------------
once = False          # this is to only display the mode ONCE on the console
while True:
  
    if globalv.button_pressed is True:    # was button pressed?
       print("Changing mode..")           # Yes
       globalv.new_mode = ricmmode.change_mode()          # new mode is set here
       print("New Mode:", globalv.new_mode)
       once = False

    if globalv.new_mode == 0 or not globalv.Robot_Name: 
       ricmmode.led2.value(1)
    else:   
#---------------------- MODE Selecion (cycles thru MODE_TABLE)
       xmode = 0     # begin at the first element of the MODE_TABLE
       mlen  = len(MODE_TABLE)/2    # Number of table entries
       while xmode < mlen:    # each entry in mode table is 2 elements
             if MODE_TABLE[xmode] == globalv.new_mode:   # compare table mode number to current mode
                func = MODE_TABLE[xmode+1]    # extract the function to call from table
                rc   = func()     # do function in MODE_TABLE
             # ------------- check return code
                if rc != 0:      # normal function codes are 0, anything negative is an ERROR, anything positive is a status
                   print("Return code from Function:",rc)
                xmode = mlen  # get out of the while loop
             xmode += 2       # point to next entry        

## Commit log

2026-08-27 Update mode descriptions and fix numbering
    [main.py]
2026-09-02 Updated Flow Charts
2026-10-15 Fix import statement for ADC in linefollow.py
    Fixed machine import
